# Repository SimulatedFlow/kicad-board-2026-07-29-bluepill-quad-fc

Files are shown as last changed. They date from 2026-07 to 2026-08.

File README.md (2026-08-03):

# 2026-07-29-bluepill-quad-fc

<!-- SF-STORE-BLOCK:BEGIN -->
## 🛒 Source-available — see before you buy

This repository contains the **full design files** of a commercial hardware board. It is **source-available, not open source**: read it, evaluate it, then buy a license to use it. See **LICENSE.md (source-available, purchase required)**.

**Get it / Buy:**
- eBay store — all our boards and PCB art: https://www.ebay.de/usr/simula-9
- Merch shop (dev & gaming): https://simulatedflow.myspreadshop.de
- Merch shop (Synthetica / EDM): https://synthetica.myspreadshop.de
- Direct / invoice (Simulated Flow UG): simulatedflow@gmail.com

_This board has no eBay item number of its own listed here — the store link above holds all current listings._

### 📬 **Free Board Documentation & Firmware Pack**

Schematics, BOMs and example-firmware docs for our STM32 carrier boards. Get it by joining the newsletter — plus a heads-up when something new ships. Double opt-in, unsubscribe in one click, no address sharing.

👉 **[Get the free pack](https://simulatedflow.teufel-engineering.com/newsletter/hardware/?q=gh)**

_© 2026 Simulated Flow UG. All rights reserved._
<!-- SF-STORE-BLOCK:END -->

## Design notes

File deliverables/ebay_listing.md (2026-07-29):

# Bluepill-QuadFC-Carrier - Leerplatine fuer STM32 Bluepill (unbestueckt/teilbestueckt, Bausatz-Basis)

STM32-Bluepill Quadcopter-Flugcontroller-Traegerboard: IMU-Modulsockel (MPU-6050), 4x ESC-PWM-Ausgaenge, RC-Empfaenger-Header, Buzzer & Status-LED - alles handloetbar.

## Highlights
- THT + SMD (Verkauf unbestueckt/teilbestueckt; schwer loetbare SMD optional fab-bestueckt)
- Passt direkt auf die STM32 'Bluepill' (2x 20-Pin-Buchsenleiste, 22,86 mm Reihenabstand)
- Schraubklemmen am Platinenrand - Kabel sauber nach aussen
- 4x M3-Befestigungsbohrungen fuer gaengige Gehaeuse
- 4-lagig (durchgehende GND- + Versorgungs-Plane, stoerarm/EMV-freundlich)

**Passendes Gehaeuse:** 80x80mm Quadcopter-Center-Plate

## Einsatzzweck
Guenstiges, komplett THT-handloetbares Flight-Controller-Traegerboard fuer Bastler/Bildung: Bluepill + GY-521-Modul aufstecken, 4 ESCs anstecken, fertig - ohne Kabelsalat, mit Beispiel-Firmware.

## Bestueckung (ca. 17 Bauteile laut Stueckliste)
- BZ: Buzzer (x1)
- C_BULK: 470uF/16V (x1)
- C_DEC: 100nF (x1)
- D_PWR: 1N5819 (x1)
- J_BP1: Bluepill_L (x1)
- J_BP2: Bluepill_R (x1)
- J_IMU: GY-521 (x1)
- J_M1: ESC_M1 (x1)
- J_M2: ESC_M2 (x1)
- J_M3: ESC_M3 (x1)
- J_M4: ESC_M4 (x1)
- J_PWR: BEC_5V_IN (x1)
- J_RX: RC_RX (x1)
- LED1: STATUS (x1)
- R_LED: 330 (x1)
- R_SCL: 4.7k (x1)
- R_SDA: 4.7k (x1)

## Lieferumfang
- 1x unbestueckte Leiterplatte (Fertigung auf Bestellung via PCBWay)
- Schaltplan als PDF + Bestueckungsliste (BOM als CSV) zum Download

**Preis:** 17 EUR (unbestueckte Leerplatine, zzgl. Versand)

Fertigung auf Bestellung - Lieferzeit nach PCBWay-Produktion. Versand als versicherter Warenversand.

## Anbieter / Impressum (gewerblicher Verkauf)
Simulated Flow UG (haftungsbeschränkt)
Zeller Straße 37 A, 77833 Ottersweier, Deutschland
Vertreten durch den Geschäftsführer: Simulated Flow
Registergericht: Amtsgericht Mannheim, HRB 758925
USt-IdNr.: DE463825106
E-Mail: simulatedflow@gmail.com
Web: https://simulatedflow.teufel-engineering.com

Gewerblicher Verkauf durch die Simulated Flow UG — es gelten das gesetzliche Widerrufsrecht (14 Tage) und die gesetzliche Gewährleistung.

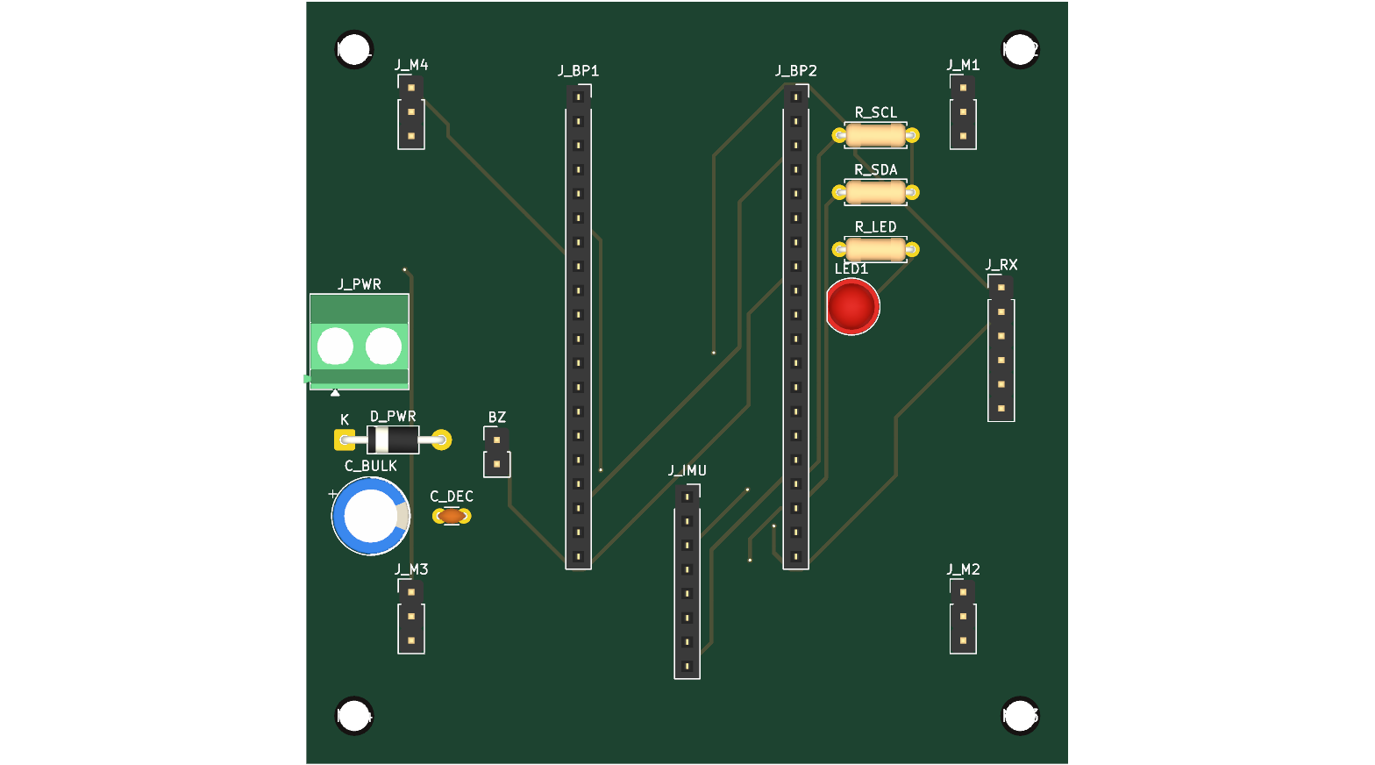
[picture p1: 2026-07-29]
deliverables/render_top.png

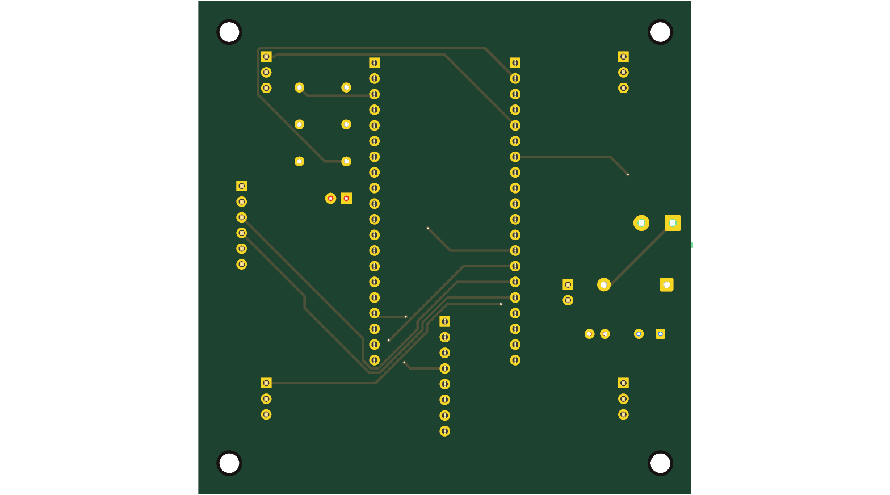
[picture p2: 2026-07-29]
deliverables/render_bottom.png

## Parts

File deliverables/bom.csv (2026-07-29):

Refs | Value | Footprint | Qty | DNP
BZ? | Buzzer | Connector_PinHeader_2.54mm:PinHeader_1x02_P2.54mm_Vertical | 1
C_BULK? | 470uF/16V | Capacitor_THT:CP_Radial_D8.0mm_P3.50mm | 1
C_DEC? | 100nF | Capacitor_THT:C_Disc_D3.0mm_W1.6mm_P2.50mm | 1
D_PWR? | 1N5819 | Diode_THT:D_DO-41_SOD81_P10.16mm_Horizontal | 1
J_BP1 | Bluepill_L | Connector_PinSocket_2.54mm:PinSocket_1x20_P2.54mm_Vertical | 1
J_BP2 | Bluepill_R | Connector_PinSocket_2.54mm:PinSocket_1x20_P2.54mm_Vertical | 1
J_IMU? | GY-521 | Connector_PinSocket_2.54mm:PinSocket_1x08_P2.54mm_Vertical | 1
J_M1 | ESC_M1 | Connector_PinHeader_2.54mm:PinHeader_1x03_P2.54mm_Vertical | 1
J_M2 | ESC_M2 | Connector_PinHeader_2.54mm:PinHeader_1x03_P2.54mm_Vertical | 1
J_M3 | ESC_M3 | Connector_PinHeader_2.54mm:PinHeader_1x03_P2.54mm_Vertical | 1
J_M4 | ESC_M4 | Connector_PinHeader_2.54mm:PinHeader_1x03_P2.54mm_Vertical | 1
J_PWR? | BEC_5V_IN | TerminalBlock_Phoenix:TerminalBlock_Phoenix_MKDS-1,5-2-5.08_1x02_P5.08mm_Horizontal | 1
J_RX? | RC_RX | Connector_PinHeader_2.54mm:PinHeader_1x06_P2.54mm_Vertical | 1
LED1 | STATUS | LED_THT:LED_D5.0mm | 1
R_LED? | 330 | Resistor_THT:R_Axial_DIN0207_L6.3mm_D2.5mm_P7.62mm_Horizontal | 1
R_SCL? | 4.7k | Resistor_THT:R_Axial_DIN0207_L6.3mm_D2.5mm_P7.62mm_Horizontal | 1
R_SDA? | 4.7k | Resistor_THT:R_Axial_DIN0207_L6.3mm_D2.5mm_P7.62mm_Horizontal | 1

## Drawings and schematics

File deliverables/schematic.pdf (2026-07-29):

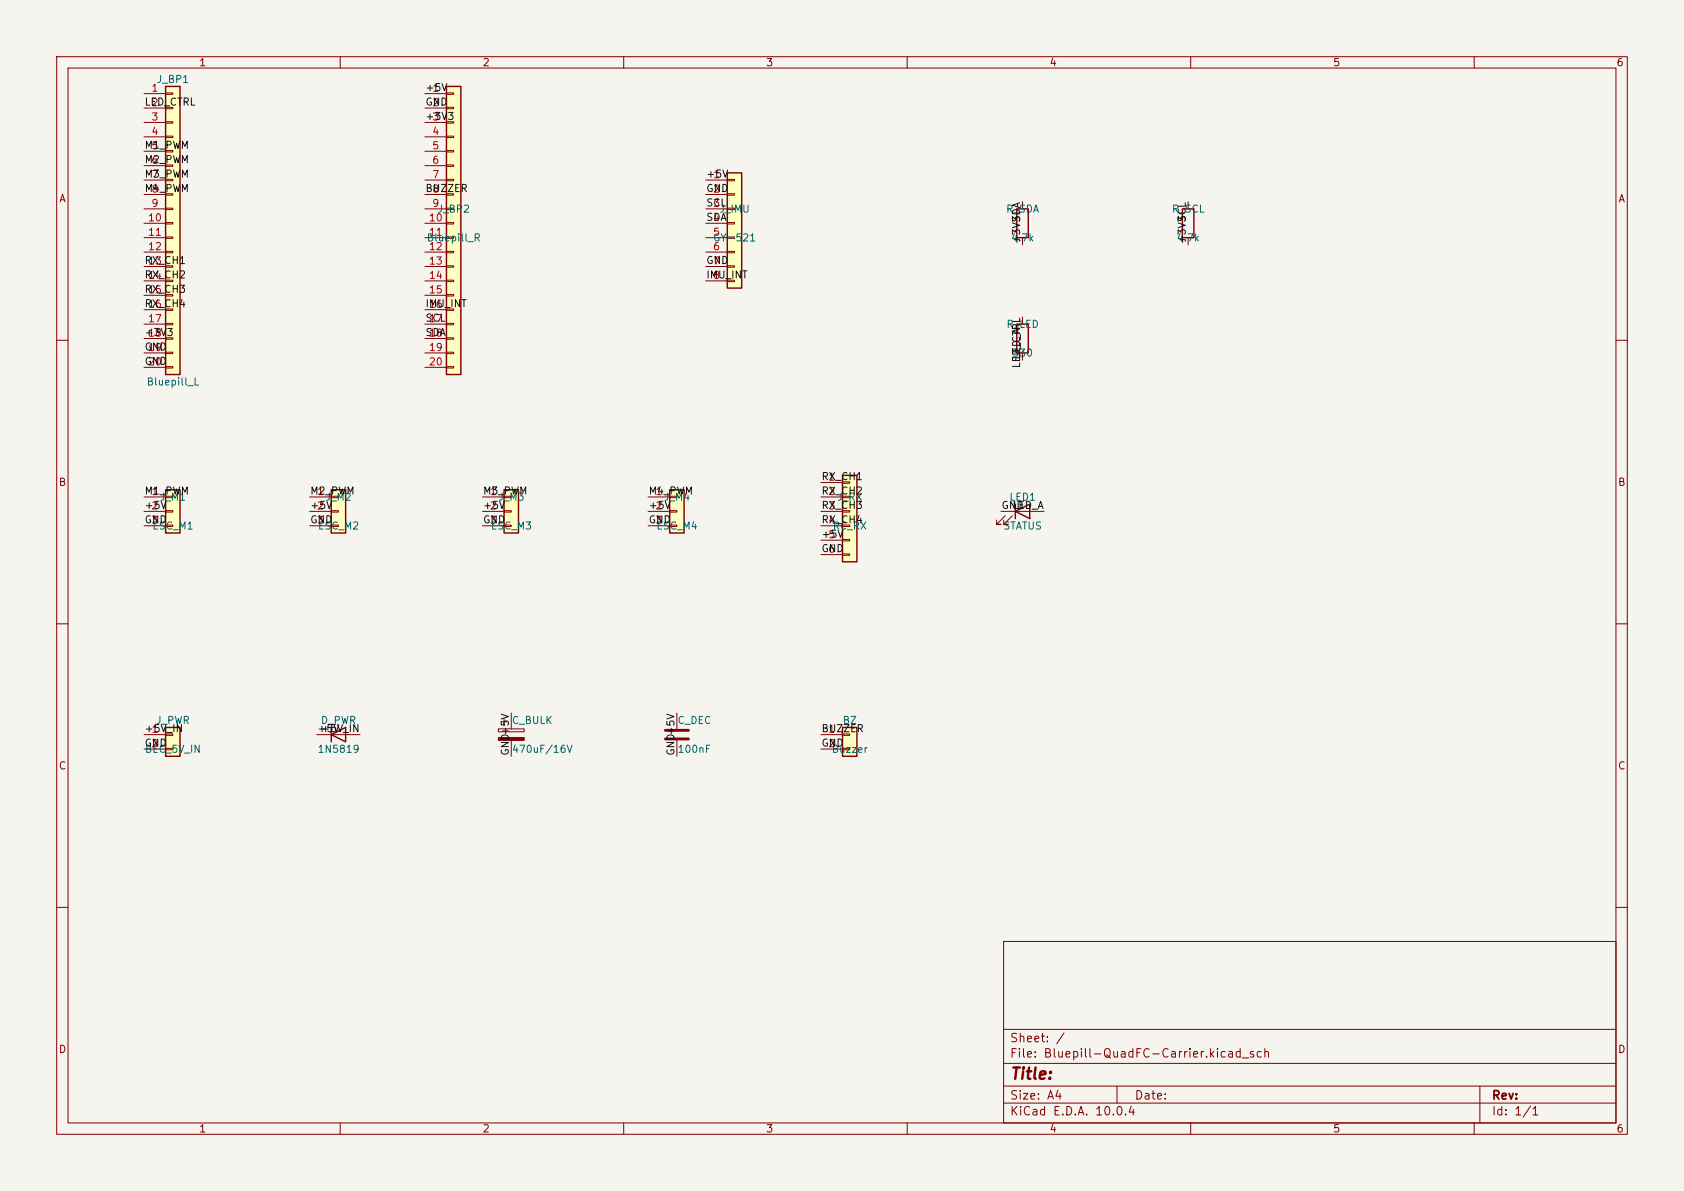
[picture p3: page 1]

Sheet: /
File: Bluepill-QuadFC-Carrier.kicad_sch
Title:

Size: A4 | Rev:
KiCad E.D.A. 10.0.4 | Id: 1/1

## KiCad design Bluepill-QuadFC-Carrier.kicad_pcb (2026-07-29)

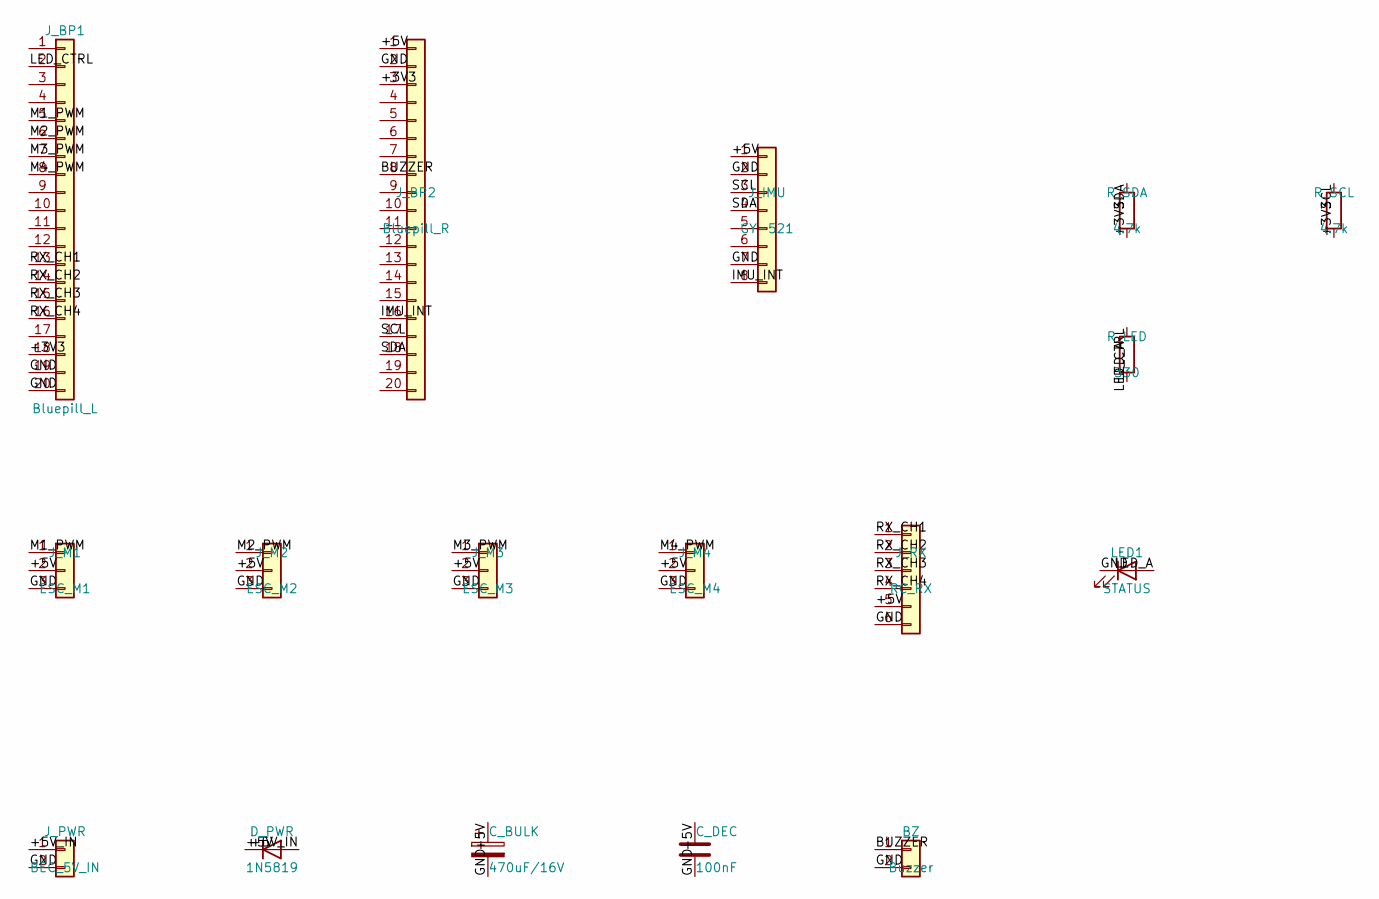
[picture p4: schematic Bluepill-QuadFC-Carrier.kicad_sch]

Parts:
BZ: Buzzer; PinHeader_1x02_P2.54mm_Vertical
C_BULK: 470uF/16V; CP_Radial_D8.0mm_P3.50mm
C_DEC: 100nF; C_Disc_D3.0mm_W1.6mm_P2.50mm
D_PWR: 1N5819; D_DO-41_SOD81_P10.16mm_Horizontal
J_BP1: Bluepill_L; PinSocket_1x20_P2.54mm_Vertical
J_BP2: Bluepill_R; PinSocket_1x20_P2.54mm_Vertical
J_IMU: GY-521; PinSocket_1x08_P2.54mm_Vertical
J_M1: ESC_M1; PinHeader_1x03_P2.54mm_Vertical
J_M2: ESC_M2; PinHeader_1x03_P2.54mm_Vertical
J_M3: ESC_M3; PinHeader_1x03_P2.54mm_Vertical
J_M4: ESC_M4; PinHeader_1x03_P2.54mm_Vertical
J_PWR: BEC_5V_IN; TerminalBlock_Phoenix_MKDS-1,5-2-5.08_1x02_P5.08mm_Horizont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
J_RX: RC_RX; PinHeader_1x06_P2.54mm_Vertical
LED1: STATUS; LED_D5.0mm
R_LED: 330; R_Axial_DIN0207_L6.3mm_D2.5mm_P7.62mm_Horizontal
R_SCL: 4.7k; R_Axial_DIN0207_L6.3mm_D2.5mm_P7.62mm_Horizontal
R_SDA: 4.7k; R_Axial_DIN0207_L6.3mm_D2.5mm_P7.62mm_Horizontal

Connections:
+3V3: J_BP1.18, J_BP2.3, R_SCL.2, R_SDA.2
+5V: C_BULK.1, C_DEC.1, D_PWR.1 (K), J_BP2.1, J_IMU.1, J_M1.2, J_M2.2, J_M3.2, J_M4.2, J_RX.5
+5V_IN: D_PWR.2 (A), J_PWR.1
BUZZER: BZ.1, J_BP2.8
GND: BZ.2, C_BULK.2, C_DEC.2, J_BP1.19, J_BP1.20, J_BP2.2, J_IMU.2, J_IMU.7, J_M1.3, J_M2.3, J_M3.3, J_M4.3, J_PWR.2, J_RX.6, LED1.1 (K)
IMU_INT: J_BP2.16, J_IMU.8
LED_A: LED1.2 (A), R_LED.2
LED_CTRL: J_BP1.2, R_LED.1
M1_PWM: J_BP1.5, J_M1.1
M2_PWM: J_BP1.6, J_M2.1
M3_PWM: J_BP1.7, J_M3.1
M4_PWM: J_BP1.8, J_M4.1
RX_CH1: J_BP1.13, J_RX.1
RX_CH2: J_BP1.14, J_RX.2
RX_CH3: J_BP1.15, J_RX.3
RX_CH4: J_BP1.16, J_RX.4
SCL: J_BP2.17, J_IMU.3, R_SCL.1
SDA: J_BP2.18, J_IMU.4, R_SDA.1

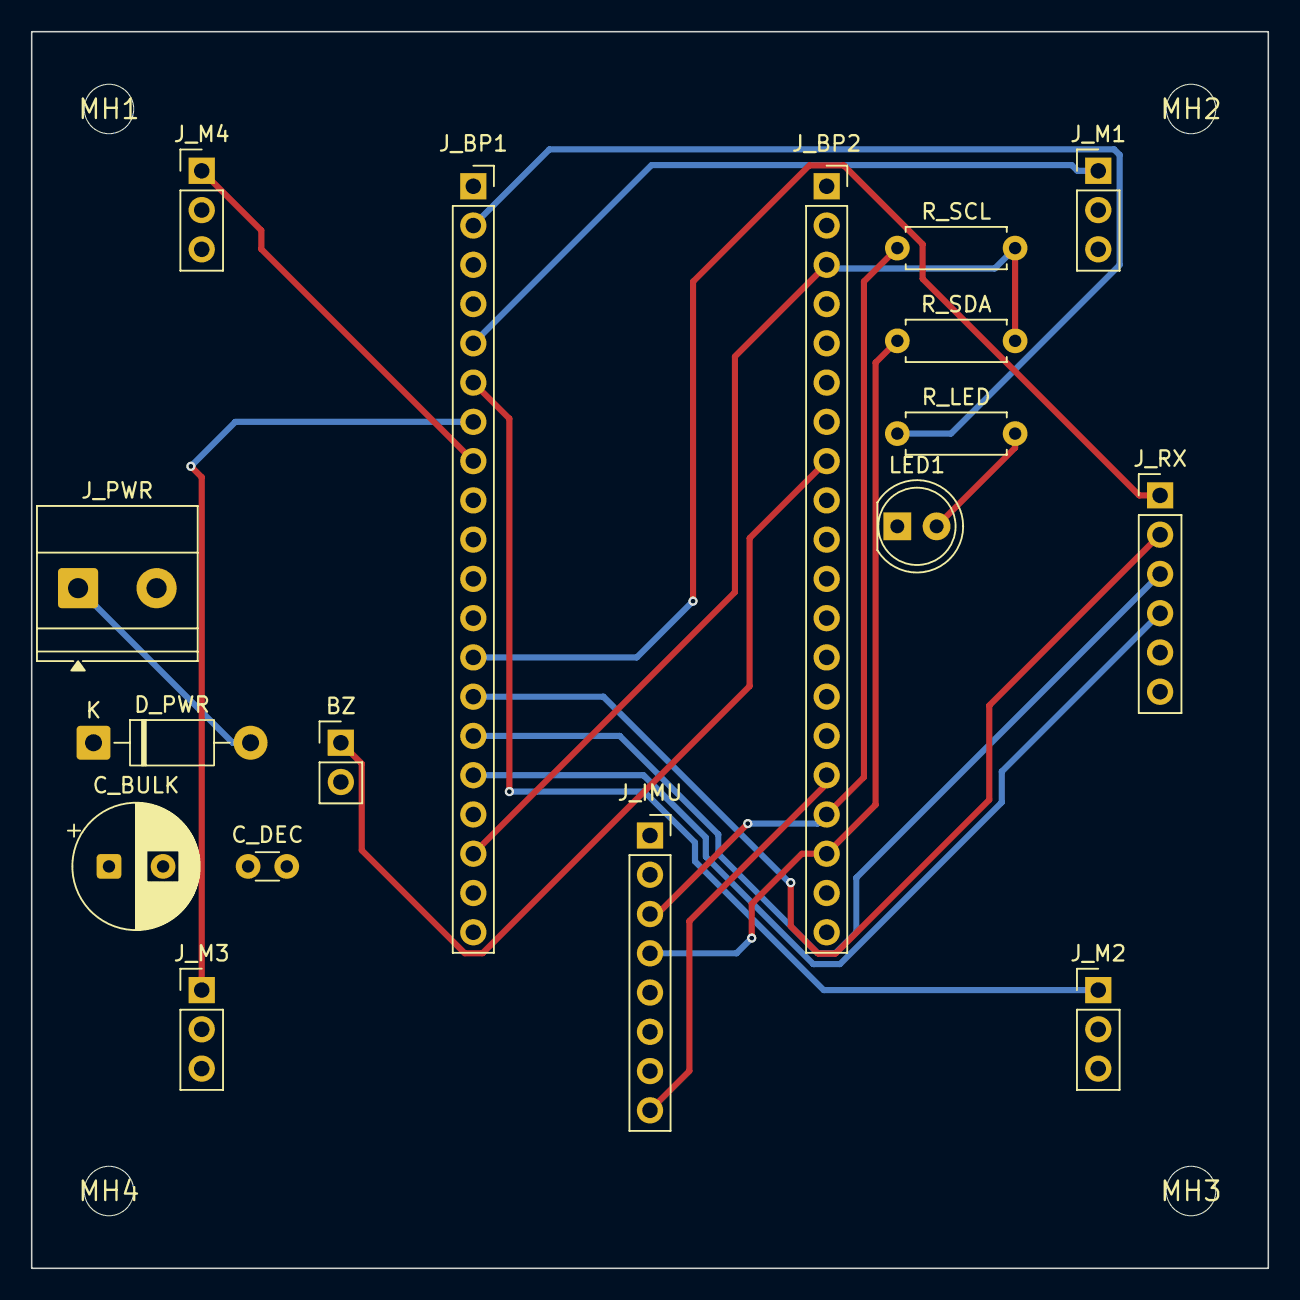
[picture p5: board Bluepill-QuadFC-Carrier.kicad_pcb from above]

Board: 4 copper layers, 80.0 x 80.0 mm, 21 parts (0 on the bottom side), 18 nets.

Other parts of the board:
MH1, MH2, MH3, MH4: MountingHole_3.2mm

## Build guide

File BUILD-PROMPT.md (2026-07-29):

```json
{
  "board_name": "Bluepill-QuadFC-Carrier",
  "one_liner": "STM32-Bluepill Quadcopter-Flugcontroller-Traegerboard mit IMU-Modulsockel, 4x ESC-PWM-Ausgaengen, RC-Empfaenger-Header, Buzzer und Status-LED.",
  "confidence": "high",
  "price_eur": 17
}
```

## BUILD-PROMPT

### 1. Board-Spezifikation & DFM
* **Abmessungen:** 80,0 mm × 80,0 mm, 4-lagig (F.Cu/B.Cu Signal, In1.Cu GND-Plane, In2.Cu +5V-Plane), FR4 1,6 mm.
* **Nur THT-Bauteile** (maximale Handloet-Tauglichkeit). Alle Sensor-/IMU-Teile als aufsteckbares Modul (Buchsenleiste), keine SMD-ICs.
* **Spurbreiten:** Signal (PWM/GPIO/I2C) ≥ 0,4 mm; Versorgung (+5V/GND) ≥ 1,0 mm.
* **Clearance:** ≥ 0,3 mm. Bauteile weiträumig platzieren, damit Freerouting sicher konvergiert.

### 2. Mechanik
* Nullpunkt (0,0) unten links. Board 80×80 mm.
* **4× M3-Bohrung** (Ø 3,2 mm) bei (5,5), (75,5), (75,75), (5,75); 3,0 mm Keepout.

### 3. Bauteilliste (nur Standard-KiCad-Bibliotheken)
1. **J_BP1, J_BP2 (Bluepill-Sockel):** 2× Buchsenleiste 1x20, Reihenabstand exakt 0.9″ (22,86 mm).
   * `Connector_PinSocket_2.54mm:PinSocket_1x20_P2.54mm_Vertical`
2. **J_IMU (IMU-Modulsockel, GY-521/MPU-6050):** 1× Buchsenleiste 1x08 (VCC, GND, SCL, SDA, XDA, XCL, AD0, INT).
   * `Connector_PinSocket_2.54mm:PinSocket_1x08_P2.54mm_Vertical`
3. **J_M1..J_M4 (ESC-Ausgaenge):** 4× Stiftleiste 1x03 (Signal, +5V, GND) fuer die 4 ESCs.
   * `Connector_PinHeader_2.54mm:PinHeader_1x03_P2.54mm_Vertical`
4. **J_RX (RC-Empfaenger):** 1× Stiftleiste 1x06 (RX_CH1..CH4, +5V, GND).
   * `Connector_PinHeader_2.54mm:PinHeader_1x06_P2.54mm_Vertical`
5. **J_PWR (BEC/5V-Eingang):** 1× Schraubklemme 2-polig (+5V, GND).
   * `TerminalBlock_Phoenix:TerminalBlock_Phoenix_MKDS-1,5-2-5.08_1x02_P5.08mm_Horizontal`
6. **D_PWR:** 1× Schottky 1N5819 (Verpolschutz in Serie zu +5V).
   * `Diode_THT:D_DO-41_SOD81_P10.16mm_Horizontal`
7. **C_BULK:** 1× Elko 470 µF / 16 V. `Capacitor_THT:CP_Radial_D8.0mm_P3.50mm`
8. **C_DEC:** 1× Keramik 100 nF. `Capacitor_THT:C_Disc_D3.0mm_W1.6mm_P2.50mm`
9. **BZ (Buzzer-Header):** 1× Stiftleiste 1x02 (aktiver Piezo-Buzzer). `Connector_PinHeader_2.54mm:PinHeader_1x02_P2.54mm_Vertical`
10. **LED1 (Status):** 1× LED 5 mm. `LED_THT:LED_D5.0mm`
11. **R_LED:** 1× 330 Ω. `Resistor_THT:R_Axial_DIN0207_L6.3mm_D2.5mm_P7.62mm_Horizontal`
12. **R_SDA, R_SCL:** 2× 4,7 kΩ I2C-Pullups nach +3V3. `Resistor_THT:R_Axial_DIN0207_L6.3mm_D2.5mm_P7.62mm_Horizontal`

### 4. Netze (Schaltplan)
* **Versorgung:** J_PWR.1(+5V_IN) → Anode D_PWR; Kathode D_PWR → Netz **+5V**. +5V → C_BULK(+), C_DEC(+), Bluepill 5V-Pin, J_IMU.VCC, J_M1..4 Pin2, J_RX.5. Alle GND (Bluepill GND, C_BULK−, C_DEC−, J_IMU.GND, J_M1..4 Pin3, J_RX.6, BZ.2, J_PWR.2) → **GND**.
* **3V3-Rail:** Bluepill 3V3 → Netz **+3V3** → R_SDA, R_SCL (Pullup-Versorgung).
* **I2C (IMU):** Bluepill **PB6=SCL** → J_IMU.SCL + R_SCL; **PB7=SDA** → J_IMU.SDA + R_SDA. J_IMU.INT → Bluepill **PB5**. J_IMU.AD0 → GND.
* **ESC-PWM (TIM2):** Bluepill **PA0→J_M1.1, PA1→J_M2.1, PA2→J_M3.1, PA3→J_M4.1**.
* **RC-Empfaenger:** Bluepill **PB0→J_RX.1, PB1→J_RX.2, PB10→J_RX.3, PB11→J_RX.4** (4 PWM-Eingaenge / oder 1 davon PPM).
* **Buzzer:** Bluepill **PA8 → BZ.1** (BZ.2 → GND).
* **Status-LED:** Bluepill **PC13 → R_LED → LED1 Anode**, LED1 Kathode → GND.

### 5. Layout
* Bluepill mittig (Reihenabstand 22,86 mm). IMU-Sockel **so zentral wie moeglich** (Vibration/Schwerpunkt), nahe Boardmitte.
* Die 4 ESC-Header (J_M1..4) in die 4 Ecken (Motorpositionen) legen, beschriftet **M1 (v.r.), M2 (h.r.), M3 (h.l.), M4 (v.l.)** auf F.SilkS.
* J_PWR und J_RX an gegenueberliegende Raender. Silk beschriften: +5V, GND, RX1-4, SCL, SDA, Buzzer.

### 6. Workflow (MCP)
1. Projekt init, Schaltplan mit klaren Net-Labels + Footprints. 2. PCB, Edge.Cuts 80×80, 4× M3. 3. 4 Lagen: In1.Cu GND-Zone + In2.Cu +5V-Zone ueber die ganze Flaeche ZUERST. 4. Bauteile weiträumig platzieren. 5. Freerouting (Signal 0,4 / Power 1,0 mm) NUR F.Cu/B.Cu. 6. DRC 0 Fehler. 7. Gerber+Drill nach ./gerbers. 8. Ehrliche Zusammenfassung.

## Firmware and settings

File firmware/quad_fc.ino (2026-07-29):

/*
 * Bluepill-QuadFC-Carrier — Beispiel-Firmware (STM32duino / Arduino_Core_STM32)
 * Simulated Flow UG · MIT-Lizenz · github.com/SimulatedFlow
 *
 * ZWECK: lauffaehige EDUKATIVE Basis fuer das QuadFC-Traegerboard. Liest die
 * MPU-6050 (I2C, PB6/PB7), 4 RC-Kanaele (PWM-Input) und steuert 4 ESCs (PA0..PA3,
 * TIM2, 50..490 Hz). Einfacher Rate-Mode-Mixer (P auf Gyro). Buzzer PA8, LED PC13.
 *
 * ⚠️ SICHERHEIT: KEIN zertifizierter Flugcontroller. Nur mit ABGENOMMENEN Propellern
 *    testen. Immer erst ARMEN, wenn Gas minimal. Auf eigene Gefahr.
 *
 * Benoetigt: Board "Generic STM32F1 (BluePill F103C8)", Lib "MPU6050" (Electronic Cats)
 *            oder "Adafruit MPU6050". Hier: rohes I2C (Wire) fuer Minimal-Abhaengigkeit.
 */
#include <Wire.h>
#include <Servo.h>

// ---- Pinbelegung (siehe BUILD-PROMPT / Board-Silk) ----
const uint8_t PIN_ESC[4] = {PA0, PA1, PA2, PA3};   // M1 vr, M2 hr, M3 hl, M4 vl
const uint8_t PIN_RX[4]  = {PB0, PB1, PB10, PB11};  // Throttle, Roll, Pitch, Yaw
const uint8_t PIN_BUZZ   = PA8;
const uint8_t PIN_LED    = PC13;
const uint8_t MPU_ADDR   = 0x68;

Servo esc[4];
volatile uint16_t rx_us[4] = {1000, 1500, 1500, 1500};

// ---- MPU-6050 ----
void mpuWrite(uint8_t reg, uint8_t val) {
  Wire.beginTransmission(MPU_ADDR); Wire.write(reg); Wire.write(val); Wire.endTransmission();
}
void mpuInit() {
  Wire.begin();
  mpuWrite(0x6B, 0x00);   // PWR_MGMT_1: wake
  mpuWrite(0x1B, 0x08);   // GYRO_CONFIG: +/-500 deg/s
}
void mpuGyro(float &gx, float &gy, float &gz) {
  Wire.beginTransmission(MPU_ADDR); Wire.write(0x43); Wire.endTransmission(false);
  Wire.requestFrom(MPU_ADDR, (uint8_t)6);
  int16_t x = (Wire.read() << 8) | Wire.read();
  int16_t y = (Wire.read() << 8) | Wire.read();
  int16_t z = (Wire.read() << 8) | Wire.read();
  gx = x / 65.5f; gy = y / 65.5f; gz = z / 65.5f;   // deg/s bei +/-500
}

// ---- RC-Eingang: einfache Pulsmessung (Polling; fuer Produktion Interrupts nutzen) ----
uint16_t readPulse(uint8_t pin) {
  unsigned long t = pulseIn(pin, HIGH, 25000UL);
  return (t >= 900 && t <= 2100) ? (uint16_t)t : 0;
}

int clampUs(int v) { return v < 1000 ? 1000 : (v > 2000 ? 2000 : v); }

void beep(int ms) { digitalWrite(PIN_BUZZ, HIGH); delay(ms); digitalWrite(PIN_BUZZ, LOW); }

void setup() {
  pinMode(PIN_BUZZ, OUTPUT); pinMode(PIN_LED, OUTPUT);
  for (int i = 0; i < 4; i++) pinMode(PIN_RX[i], INPUT);
  for (int i = 0; i < 4; i++) { esc[i].attach(PIN_ESC[i], 1000, 2000); esc[i].writeMicroseconds(1000); }
  mpuInit();
  beep(80); delay(120); beep(80);   // Boot-Signal, ESCs auf min (Arming)
  delay(2000);
}

void loop() {
  // 1) RC lesen
  for (int i = 0; i < 4; i++) { uint16_t p = readPulse(PIN_RX[i]); if (p) rx_us[i] = p; }
  int thr = rx_us[0], roll = rx_us[1] - 1500, pitch = rx_us[2] - 1500, yaw = rx_us[3] - 1500;

  // 2) Gyro lesen
  float gx, gy, gz; mpuGyro(gx, gy, gz);

  // 3) Rate-Mode P-Regler (nur Demo; echte Firmware: PID + Filter + Fail-safe)
  const float Kp = 0.9f;
  int uRoll  = (int)(roll  * 0.5f - Kp * gx);
  int uPitch = (int)(pitch * 0.5f - Kp * gy);
  int uYaw   = (int)(yaw   * 0.5f - Kp * gz);

  // 4) X-Quad-Mixer (M1 vr, M2 hr, M3 hl, M4 vl)
  int m1 = clampUs(thr - uRoll - uPitch - uYaw);
  int m2 = clampUs(thr - uRoll + uPitch + uYaw);
  int m3 = clampUs(thr + uRoll + uPitch - uYaw);
  int m4 = clampUs(thr + uRoll - uPitch + uYaw);

  // 5) Fail-safe: kein/zu kleines Gas -> Motoren aus
  if (thr < 1050) { m1 = m2 = m3 = m4 = 1000; }
  esc[0].writeMicroseconds(m1); esc[1].writeMicroseconds(m2);
  esc[2].writeMicroseconds(m3); esc[3].writeMicroseconds(m4);

  digitalWrite(PIN_LED, (millis() / 250) & 1);   // Heartbeat
  delay(5);   // ~200 Hz Loop
}
